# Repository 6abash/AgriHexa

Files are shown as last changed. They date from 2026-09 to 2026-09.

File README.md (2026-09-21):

# AgriHexa

A six-legged agricultural robot: custom carbon-fiber hexapod chassis,
dual-MCU control/kinematics stack, IMU-stabilized walking, and
satellite-image path planning for autonomous fieldwork. Originally
based on the open-source [Make Your Pet](https://github.com/makeyourpet)
platform, substantially redesigned and re-engineered for planting and
terrain navigation.

## Achievements

🏆 **1st Place, Open Category — WRCC 2026**, for outstanding autonomous
performance.

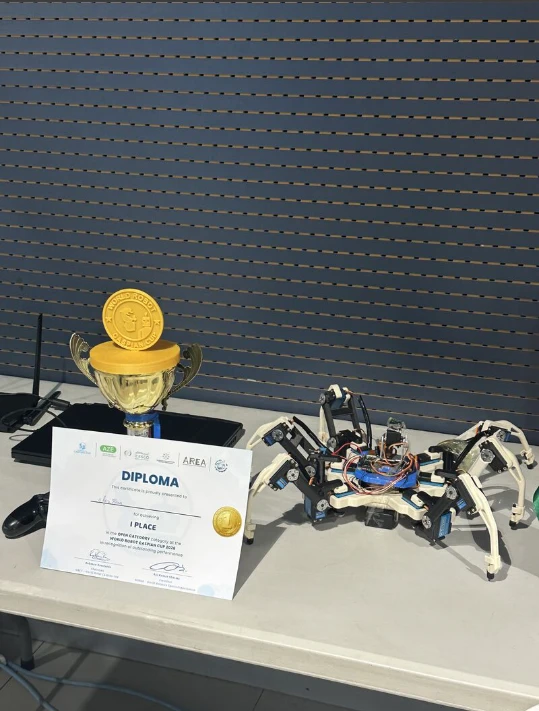
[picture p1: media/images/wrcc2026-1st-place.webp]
AgriHexa — 1st Place, Open Category, WRCC 2026


## Features

- **Planting mechanism** — deploys small (3–5 mm radius) circular
  seeds/plants in a hummus-like growing medium as the robot traverses
  a field.
- **IMU-stabilized walking** — a BNO055 IMU feeds dual PID loops
  (pitch/roll) so the body stays level while walking or standing on
  uneven ground.
- **Autonomous terrain navigation** — an A* planner turns a satellite
  image (e.g. a Google Maps screenshot) into a terrain-cost grid,
  lets an operator drop multiple waypoints, and routes the robot along
  the path with the least incline/decline and roughest terrain.
- **Dual-MCU control** — an ESP32 handles Wi-Fi, PS4 teleop, and IMU
  stability; a Servo2040 (RP2040) is dedicated to per-leg inverse
  kinematics and gait generation.
- **Carbon-fiber legs with steel servo horns**, driven by 18x DS3235
  servos (3 per leg x 6 legs).

## Architecture

```
Satellite image ──▶ [navigation] A* planner ──Wi-Fi (TCP)──▶ [firmware] ESP32
                                                                   │  control + IMU PID
                                                                   │  UART (RobotState)
                                                                   ▼
                                                        [kinematics] Servo2040
                                                          IK solve + gait ──▶ 18x DS3235
```

PS4 controller input always takes priority over autonomous commands —
touching the controller instantly cancels any in-progress autonomous
move.

## Media

<video src="media/videos/short-pitch.mp4" controls width="500"></video>
<video src="media/videos/stability-system.mp4" controls width="500"></video>

## Repository structure

| Path | Contents |
|---|---|
| [`/firmware`](firmware) | ESP32 control MCU: Wi-Fi, PS4 teleop, BNO055 stability PID |
| [`/kinematics`](kinematics) | Servo2040 MCU: per-leg inverse kinematics, tripod gait |
| [`/navigation`](navigation) | Satellite-image A* terrain path planner (ground station) |
| [`/simulation`](simulation) | MATLAB one-leg IK visualizer; full hexapod Simscape model in progress |
| [`/hardware`](hardware) | BOM, [CAD](hardware/cad) (partial, more coming), wiring diagram in progress |
| [`/docs`](docs) | [Design differences from Make Your Pet](docs/design-differences.md) |
| [`/media`](media) | Photos and demo videos |

## Getting started

1. **Firmware (ESP32)** — see [`firmware/README.md`](firmware/README.md)
   for wiring, the `secrets.h` setup, and PlatformIO build steps.
2. **Kinematics (Servo2040)** — see
   [`kinematics/README.md`](kinematics/README.md) for the leg model,
   gait, and CMake/Pico SDK build steps.
3. **Navigation (ground station)** — see
   [`navigation/README.md`](navigation/README.md) to run the A*
   satellite planner.
4. **Simulation** — see [`simulation/README.md`](simulation/README.md)
   for the MATLAB one-leg IK visualizer.

## Credits

- IK/gait approach adapted from the open-source
  [Make Your Pet](https://github.com/makeyourpet) hexapod platform.
- Built by [6abash](https://github.com/6abash).

## License

[MIT](LICENSE)

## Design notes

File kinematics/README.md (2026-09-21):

# Kinematics — Servo2040 Inverse Kinematics MCU

The Servo2040 (RP2040, Pimoroni) is dedicated entirely to leg math and
servo output. It receives a fused `RobotState` packet from the ESP32
over UART every control cycle and turns it into 18 servo angles.

## Leg model

Each leg is a 3-DOF serial chain: coxa (`L1`), femur (`L2`), tibia
(`L3`), solved with closed-form inverse kinematics
(`solve_ik(x, y, z, side)` in `servo2040/main.cpp`):

```
L1 = 4.0   // coxa
L2 = 8.0   // femur
L3 = 12.0  // tibia
```

Given a target foot position in the leg's local frame, `solve_ik`
returns hip/thigh/shin (`h`, `t`, `s`) angles, or marks the target
unreachable (`valid = false`) if it falls outside the leg's workspace
(`d > L2+L3` or `d < |L2-L3|`).

Six legs (`LF`, `LB`, `LM`, `RM`, `RF`, `RB`), three servos each = the
project's 18x DS3235. Per-leg Cartesian trims (`xyz_offset`) let each
leg be calibrated independently to absorb small assembly tolerances,
applied before the IK solve rather than as a post-hoc angle offset.

## Gait

`walk_step()` drives a tripod gait: legs are split into two phase
groups (`gait_offsets`), alternating stance (linear ground contact,
carrying the body) and swing (a quintic Bezier arc lifting the foot by
`STEP_H` and carrying it forward). Body pitch/roll from the ESP32's
IMU PID are folded into every leg's target position every cycle so the
body stays level over uneven ground while walking or standing still
(`stand_still()`).

`startup_sequence()` eases every leg from a folded rest position to
its standing pose over 200 interpolated steps, avoiding a snap-to-pose
power-on jolt.

## UART protocol

Listens on `uart1` (pins 20/21, 115200 baud) for the same packed
`RobotState` struct the ESP32 sends (see
[`/firmware`](../firmware/README.md#protocol)), framed by a `0xAA`
header / `0x55` footer byte pair.

## Building

Requires the [Raspberry Pi Pico SDK](https://github.com/raspberrypi/pico-sdk)
and the [Pimoroni Pico libraries](https://github.com/pimoroni/pimoroni-pico)
(for `ServoCluster`).

```bash
cd kinematics/servo2040
mkdir build && cd build
cmake -DPICO_SDK_PATH=/path/to/pico-sdk \
      -DPIMORONI_PICO_PATH=/path/to/pimoroni-pico ..
make -j4
# flash Hexapod_OS.uf2 to the Servo2040 in BOOTSEL mode
```

Built and tested against Pico SDK 1.5.1.

Alternatively set `PICO_SDK_FETCH_FROM_GIT=ON` /
`PIMORONI_PICO_FETCH_FROM_GIT=ON` to have CMake pull both SDKs
automatically.

## Credit

The IK/gait approach on the Servo2040 builds on ideas from the
open-source [Make Your Pet](https://github.com/makeyourpet) hexapod
platform, substantially reworked for AgriHexa's leg geometry, dual-MCU
split, and Cartesian trim/stability integration.

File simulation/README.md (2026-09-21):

# Simulation

## One-leg IK visualizer (`/one_leg`)

`IK_visualizer.m` is a MATLAB tool for validating the 3-DOF leg
inverse-kinematics solution (hip/thigh/shin) used on the Servo2040
before it ever touches hardware. It renders a single leg in 3D and
gives you live sliders for target X/Y/Z plus a knee-up/knee-down
toggle, redrawing the link chain and annotating each joint angle
(θ_H, θ_T, θ_S) in degrees as you move them. It shares the same
planar-IK-after-hip-rotation approach as `kinematics/servo2040/main.cpp`
(`solve_ik`), so it doubles as a sanity check when leg geometry
(`L2`, `L3`) or the knee convention changes.

```matlab
IK_visualizer
```

## Full hexapod (Simscape) — in progress

The one-leg model has been scaled up into a full hexapod Simscape
Multibody simulation (all 6 legs, body dynamics, gait), currently in
progress. It'll land in this folder once the model is ready, along
with the CAD it's built from.

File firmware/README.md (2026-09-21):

# Firmware — ESP32 Control MCU

The ESP32 is the "brain" of AgriHexa's dual-MCU control stack. It owns
everything that isn't leg math:

- **Stability**: reads a BNO055 IMU and runs two independent PID loops
  (pitch, roll) to compute body-leveling corrections in real time.
- **Teleop**: pairs with a PS4 controller for manual driving (stride,
  strafe, ride height).
- **Autonomy bridge**: runs a TCP server on port 80 that accepts move
  commands (`F`, `B`, `L`, `R`, `FR`, `FL`, `BR`, `BL`, `S`) from the
  ground-station A* planner in [`/navigation`](../navigation), and
  ACKs each completed step back over the socket.
- **Fusion**: packs pitch/roll/stride/strafe/height/walking into a single
  `RobotState` struct and streams it over UART to the Servo2040
  (see [`/kinematics`](../kinematics)), which solves inverse kinematics
  and drives the 18 servos.

PS4 input always takes priority — touching the controller instantly
cancels any in-progress autonomous move.

## Hardware

| Signal | ESP32 Pin |
|---|---|
| I2C SDA (BNO055)| 18 |
| I2C SCL (BNO055)| 21 |
| UART TX -> Servo2040 | 16 |
| UART RX <- Servo2040 | 23 |
| Relay | 27 |

## Building

This is a PlatformIO project.

```bash
cd firmware/esp32
cp include/secrets.h.example include/secrets.h   # fill in your own Wi-Fi creds
pio run -t upload
pio device monitor
```

`secrets.h` is gitignored on purpose — never commit real Wi-Fi
credentials. Only `secrets.h.example` is tracked.

## Protocol

`RobotState` (packed, sent every loop iteration over UART2 @ 115200):

```c
struct __attribute__((packed)) RobotState {
    uint8_t header;      // 0xAA
    float body_pitch;
    float body_roll;
    float body_yaw;
    float stride;
    float strafe;
    float height;
    uint8_t walking;
    uint8_t footer;       // 0x55
};
```

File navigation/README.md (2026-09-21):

# Navigation — Satellite Terrain Path Planner

A ground-station Python tool that lets an operator plan an autonomous
mission for AgriHexa directly on a satellite/aerial image, then drives
the robot through it live over Wi-Fi.

## Pipeline

1. **Image ingestion** — loads a satellite screenshot (e.g. cropped
   from Google Maps) of the target field. If none is found, a synthetic
   terrain photo is generated so the planner can still be demoed.
2. **Terrain costing** — resizes the image to a grid and derives a
   per-cell traversal cost from two cues: an HSV green mask (vegetation
   = easier ground) and Sobel gradient magnitude (roughness = a proxy
   for slope/incline, penalized more heavily). Cells above a threshold
   are marked impassable, so A* is steered around steep terrain and
   obstacles, not just toward the shortest line.
3. **Waypoint selection** — `matplotlib.ginput` lets the operator click
   as many waypoints as they like directly on the satellite image.
4. **Path planning** — 8-connected A* (`a_star_search`) runs between
   each consecutive waypoint pair, using terrain cost (not just
   distance) as the edge weight, so the resulting path favors flat,
   vegetated ground and minimizes climbs/descents.
5. **Mission execution** — the grid path is translated into the
   robot's move vocabulary (`F/B/L/R/FR/FL/BR/BL/S`) and streamed step
   by step over a TCP socket to the ESP32 (see [`/firmware`](../firmware)),
   waiting for an `ACK` after each step before sending the next. A live
   dual-panel animation (satellite view + cost map) tracks the robot's
   position as it moves.

## Running

```bash
cd navigation
pip install -r requirements.txt
python satellite_path_planner.py
```

Set `mock_hardware=True` in the `execute_mission_and_animate` call at
the bottom of the script to dry-run the planner and animation without
an open Wi-Fi socket to real hardware. Update `esp32_ip` to match the
static IP configured in the ESP32 firmware.

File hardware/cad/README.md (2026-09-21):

# CAD

STEP files for AgriHexa's mechanical parts, exported from SolidWorks.
More parts land here as they're finalized — this is a first batch, not
the full assembly.

| File | Part |
|---|---|
| `frame.STEP` | Main body frame |
| `servo_body.STEP` | Servo mounting body |
| `servo_back_hole.STEP` | Servo back-hole mount |
| `coxa_left.STEP` | Left-side coxa (hip) link |
| `coxa_right.STEP` | Right-side coxa (hip) link |
| `femur.STEP` | Femur (thigh) link |
| `tibia.STEP` | Tibia (shin) link |

Note the left/right coxa are separate parts, not a single mirrored
part — keep that in mind if you're assembling or referencing them
elsewhere (e.g. the Simscape model).

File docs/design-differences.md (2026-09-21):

# Design differences from Make Your Pet

AgriHexa uses the open-source [Make Your Pet](https://github.com/makeyourpet)
hexapod as a starting platform — credit to them for open-sourcing the
design. Everything below is what changed to turn it from a
phone-controlled hexapod into a standalone system built for precision
farming.

## The platform is a means to an end

Make Your Pet's design is a hexapod platform; AgriHexa uses that
platform to solve a specific problem — precision farming (targeted
planting, terrain-aware autonomous navigation). The mechanical base
carried over, but almost everything around it changed to support that.

## Removing the phone dependency

The original Make Your Pet build relies entirely on a smartphone: the
Chica app supplies the sensor data (including the IMU) the robot needs
to operate, and the phone also powers the Servo2040. That works for a
demo platform, but it isn't something you can actually deploy as a
farming system — there's no phone in the loop.

To make it a standalone system, AgriHexa adds:

- **An ESP32 as a dedicated control MCU** — replacing the phone as the
  thing that talks Wi-Fi, runs the stability control loop, and accepts
  teleop/autonomous commands.
- **A standalone BNO055 IMU** — replacing the phone's IMU as the
  stability sensor, feeding the ESP32's pitch/roll PID loops directly.
- **A buck converter (7.4V -> 5V)** — since there's no longer a phone
  to charge the Servo2040, and the system now carries more electronics
  (ESP32, IMU) than the original design, a buck converter steps the
  main 7.4V battery rail down to the 5V logic supply those components
  need.

Everything else in the electrical/control architecture — the Servo2040
handling inverse kinematics and driving the servos — follows the same
approach as Make Your Pet.

## Mechanical changes

- **Steel servo horns instead of plastic** — the stock plastic horns
  failed under the stall torque of the DS3235 servos. Steel horns were
  a necessary swap, not a preference.
- **Revised mounting holes** — hole sizing was reworked to 3mm in
  SolidWorks for a more reliable fastener fit.
- **CF-PETG as the print material** — arrived at by trial and error as
  the best-performing material for the structural/printed parts.

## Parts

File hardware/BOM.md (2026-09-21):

# Bill of Materials

Quantities below are derived directly from the design (6 legs x 3
servos, etc.).

| # | Part | Spec / Notes | Qty |
|---|---|---|-----|
| 1 | Servo | DS3235 digital servo | 18 (3 x 6 legs) |
| 2 | Control MCU | ESP32 dev board (Wi-Fi, PS4 teleop, BNO055 stability PID) | 1 |
| 3 | Kinematics MCU | Pimoroni Servo2040 (RP2040, 18-channel servo driver) | 1 |
| 4 | IMU | Adafruit BNO055 breakout | 1 |
| 5 | Buck converter | 7.4V -> 5V, powers ESP32 + BNO055 + logic rail | 1 |
| 6 | Battery | 2S LiPo, 7.4V nominal | 1 |
| 7 | Relay | Switches planting mechanism / auxiliary load off ESP32 GPIO27 | 1 |
| 8 | Servo horn | Steel (replaces stock plastic — failed under DS3235 stall torque) | 18 |
| 9 | Leg tube/link | Carbon fiber | 6 legs x 3 links = 18 |
| 10 | Structural/printed parts | CF-PETG (chosen over plain PETG/PLA by trial and error) | as needed |
| 11 | Controller | PS4 DualShock 4 (teleop) | 1 |
| 12 | Planting mechanism | Servo-driven dispenser for 3–5mm radius plants | 1 |
| 13 | Fasteners | M3 hardware (3mm mounting holes, SolidWorks-revised) | as needed |
| 14 | Wiring | Servo extension leads, JST/XT30 connectors, heat shrink | as needed |

Add rows as the hardware doc / CAD get finalized (mounting hardware,
connectors, standoffs, etc. tend to only become exact once the CAD is
locked).

## Wiring diagram

Not built yet. Recommended tool: **Fritzing** — it has parts for ESP32
dev boards and hobby servos, and produces a breadboard-style diagram
that's far more readable in a README than a raw schematic. Export as
SVG/PNG and drop it here as `hardware/wiring-diagram.svg`, referenced
from the root README.

If a proper schematic (net labels, real symbols for the buck converter,
BNO055, relay) is wanted later, KiCad is the step up from Fritzing.

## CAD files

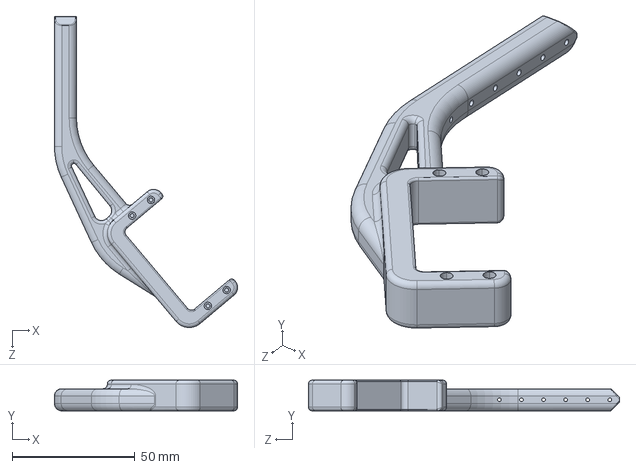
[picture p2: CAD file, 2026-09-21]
hardware/cad/tibia.STEP
74.6 x 12.5 x 126.7 mm

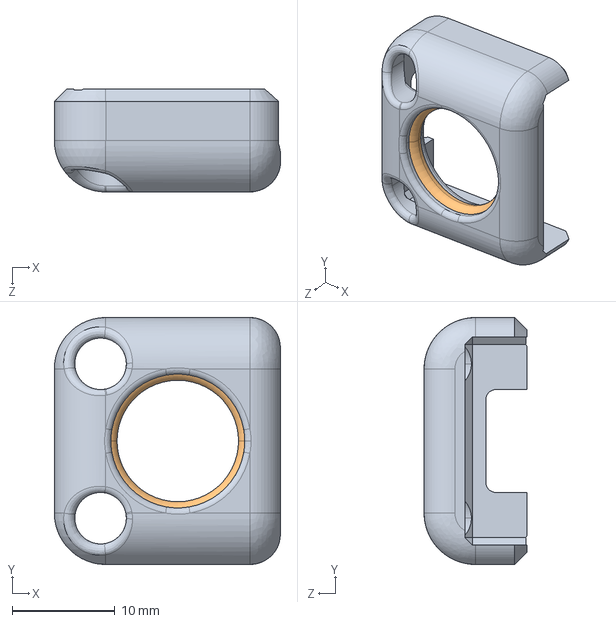
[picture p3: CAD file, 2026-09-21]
hardware/cad/servo_back_hole.STEP
22.0 x 24.0 x 10.0 mm

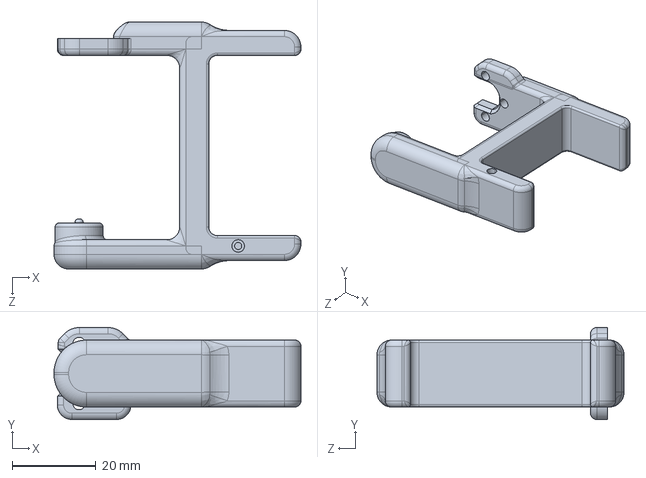
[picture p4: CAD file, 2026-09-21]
hardware/cad/coxa_left.STEP
59.0 x 22.0 x 59.0 mm

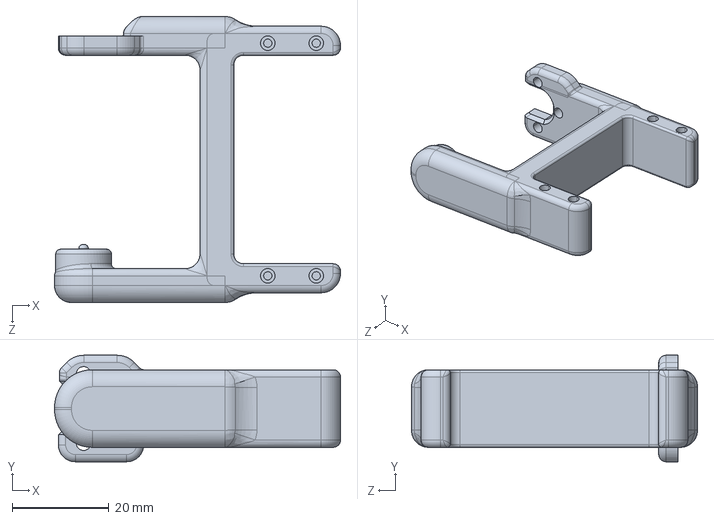
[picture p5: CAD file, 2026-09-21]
hardware/cad/coxa_right.STEP
59.0 x 22.0 x 59.0 mm

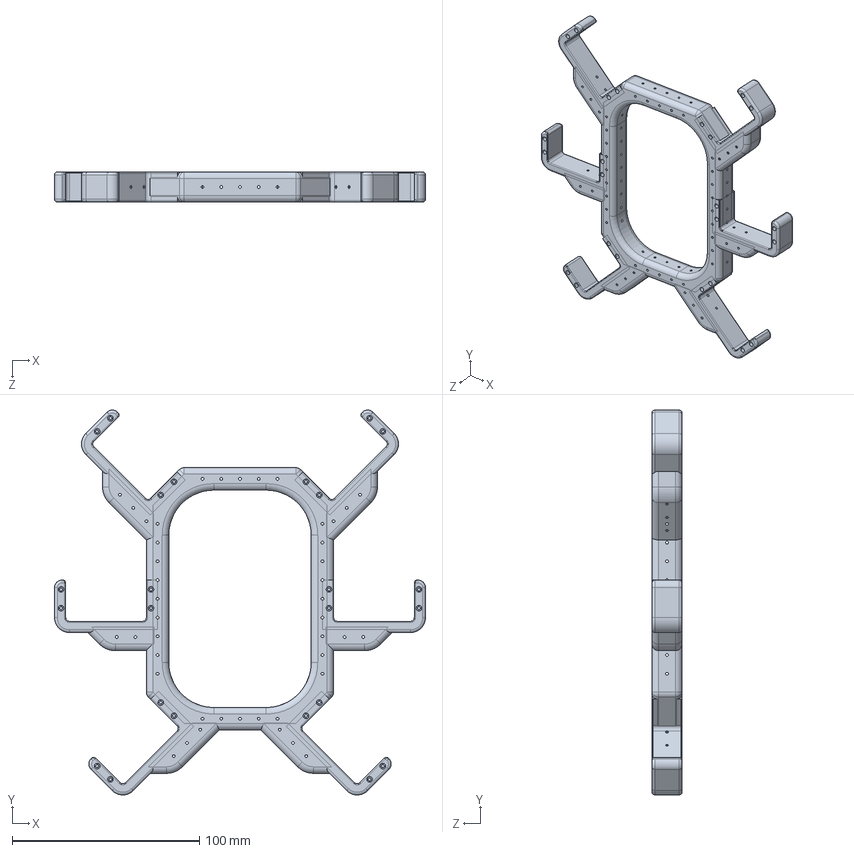
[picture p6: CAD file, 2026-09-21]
hardware/cad/frame.STEP
198.0 x 205.4 x 16.0 mm

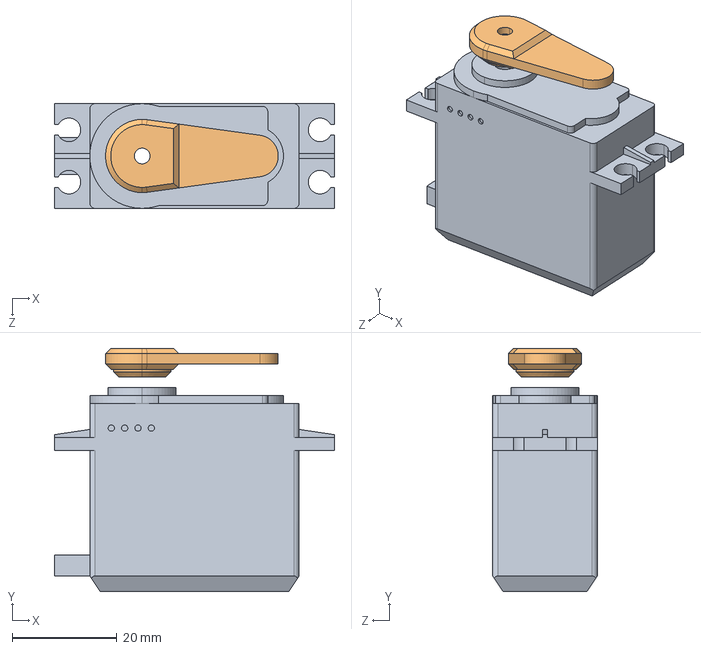
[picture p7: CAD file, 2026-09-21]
hardware/cad/servo_body.STEP
53.5 x 46.5 x 20.0 mm

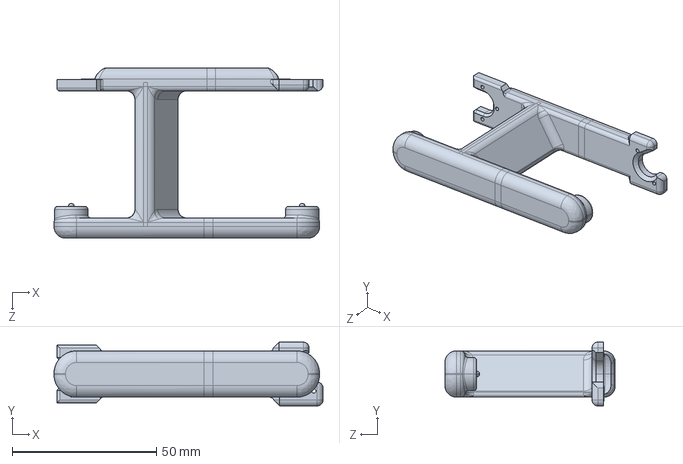
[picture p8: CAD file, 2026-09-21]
hardware/cad/femur.STEP
93.2 x 22.1 x 59.0 mm

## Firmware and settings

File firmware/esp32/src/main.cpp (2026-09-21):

// AgriHexa - ESP32 Control MCU
//
// Responsibilities:
//   - IMU (BNO055) stability PID -> body pitch/roll correction
//   - PS4 controller teleop input
//   - Wi-Fi TCP server accepting autonomous move commands from the
//     ground-station A* planner (see /navigation)
//   - Packs the unified RobotState and streams it over UART to the
//     Servo2040 (see /kinematics), which solves IK and drives the servos
//
#include <Arduino.h>
#include <Wire.h>
#include <Adafruit_Sensor.h>
#include <Adafruit_BNO055.h>
#include <PS4Controller.h>
#include <WiFi.h>
#include "secrets.h"

#define RELAY_PIN    27
#define I2C_SDA      18
#define I2C_SCL      21
#define SERVO_TX     16
#define SERVO_RX     23

// ==========================================
// 1. HARDWARE SENSORS & PID
// ==========================================
float filtered_pitch = 0.0f;
float filtered_roll  = 0.0f;
const float ALPHA    = 0.1f;
const float DEADBAND = 2.0f;

Adafruit_BNO055 bno = Adafruit_BNO055(55, 0x28, &Wire);

struct PID {
    float kp, ki, kd;
    float prev_error;
    float integral;
};

PID pitch_pid = {0.01f, 0.0f, 0.0008f, 0.0f, 0.0f};
PID roll_pid  = {0.01f, 0.0f, 0.0008f, 0.0f, 0.0f};

uint32_t zero_streak = 0;
const uint32_t ZERO_LIMIT = 50;
bool bno_initialized = false;
unsigned long last_time = 0;

float compute_pid(PID &pid, float error, float dt) {
    pid.integral += error * dt;
    pid.integral = constrain(pid.integral, -0.5f, 0.5f);
    float derivative = (error - pid.prev_error) / dt;
    derivative = constrain(derivative, -50.0f, 50.0f);
    pid.prev_error = error;
    return (pid.kp * error) + (pid.ki * pid.integral) + (pid.kd * derivative);
}

void attempt_recovery() {
    Serial.println("[BNO055] Resetting...");
    bno_initialized = false;
    Wire.end(); delay(500);
    Wire.begin(I2C_SDA, I2C_SCL); Wire.setClock(100000); delay(100);
    if (bno.begin()) {
        bno.setExtCrystalUse(true);
        bno_initialized = true;
        zero_streak = 0;
        Serial.println("[BNO055] Recovery successful.");
    }
}

// ==========================================
// 2. KINEMATICS DATA STRUCTURE
// ==========================================
struct __attribute__((packed)) RobotState {
    uint8_t header;
    float body_pitch;
    float body_roll;
    float body_yaw;
    float stride;
    float strafe;
    float height;
    uint8_t walking;
    uint8_t footer;
};

RobotState state = {0xAA, 0.0f, 0.0f, 0.0f, 0.0f, 0.0f, -12.0f, 0, 0x55};

// ==========================================
// 3. NETWORK & NON-BLOCKING VARIABLES
// ==========================================
const char* ssid     = WIFI_SSID;
const char* password = WIFI_PASSWORD;

// Static IP for the robot on the field network
IPAddress local_IP(192, 168, 0, 51);
IPAddress gateway(192, 168, 0, 1);
IPAddress subnet(255, 255, 255, 0);

WiFiServer server(80);
WiFiClient active_client; // Persistent TCP client

// Non-blocking timer variables
const unsigned long STRIDE_DELAY_MS = 1500;
unsigned long moveStartTime = 0;
bool isAutoMoving = false; // Tracks if a Wi-Fi command is currently executing
float auto_stride = 0.0f;
float auto_strafe = 0.0f;

// ==========================================
// 4. PS4 CONTROLLER
// ==========================================
float ps4_stride = 0.0f;
float ps4_strafe = 0.0f;
float height_cmd = -12.0f;
bool  ps4_walking = false;

const float DEAD_ZONE     = 10.0f;
const float STRIDE_SCALE  = 0.007f;
const float STRAFE_SCALE  = -0.007f;
const float HEIGHT_SCALE  = 0.04f;
const float HEIGHT_MIN    = -18.0f;
const float HEIGHT_MAX    = -6.0f;

void read_ps4() {
    if (!PS4.isConnected()) return;
    float lx = PS4.LStickX();
    float ly = PS4.LStickY();
    float ry = PS4.RStickY();

    if (fabsf(ly) > DEAD_ZONE) ps4_stride = constrain(-ly * STRIDE_SCALE, -1.0f, 1.0f);
    else ps4_stride = 0.0f;

    if (fabsf(lx) > DEAD_ZONE) ps4_strafe = constrain(lx * STRAFE_SCALE, -1.0f, 1.0f);
    else ps4_strafe = 0.0f;

    ps4_walking = (fabsf(ly) > DEAD_ZONE) || (fabsf(lx) > DEAD_ZONE);

    if (fabsf(ry) > DEAD_ZONE) {
        height_cmd = constrain(height_cmd + (-ry) * HEIGHT_SCALE * 0.01f, HEIGHT_MIN, HEIGHT_MAX);
    }
}

// ==========================================
// SETUP ROUTINE
// ==========================================
void setup() {
    Serial.begin(115200);

    // Servo UART bridge to the Servo2040: SERVO_RX is where the ESP32
    // receives, SERVO_TX is where the ESP32 transmits.
    Serial2.begin(115200, SERIAL_8N1, SERVO_RX, SERVO_TX);

    // Initialize Hardware Peripherals
    Wire.begin(I2C_SDA, I2C_SCL);
    if (bno.begin()) {
        bno.setExtCrystalUse(true);
        bno_initialized = true;
    }

    // Initialize PS4 with a dummy MAC to prevent crashing
    PS4.begin("03:03:03:03:03:03");

    // Network Setup
    if (!WiFi.config(local_IP, gateway, subnet)) {
        Serial.println("STA Failed to configure static IP");
    }
    WiFi.begin(ssid, password);
    Serial.print("Connecting to Wi-Fi...");
    while (WiFi.status() != WL_CONNECTED) { delay(500); Serial.print("."); }

    Serial.println("\nWiFi Connected! IP: ");
    Serial.println(WiFi.localIP());
    server.begin();
    Serial.println("Awaiting autonomous Python commands on Port 80...");
}

// ==========================================
// MAIN LOOP: WiFi + PS4 + PID
// ==========================================
void loop() {
    // 1. Read PS4 Controller First
    read_ps4();

    // 2. Wi-Fi Control (Non-Blocking)
    // Only accept incoming commands if PS4 is idle
    if (ps4_stride == 0.0f && ps4_strafe == 0.0f) {

        // Grab incoming connection if none is active
        if (!active_client || !active_client.connected()) {
            active_client = server.available();
        }

        // Listen for new commands ONLY if the robot is not currently taking a step
        if (active_client && active_client.connected() && !isAutoMoving) {
            if (active_client.available() > 0) {
                String input = active_client.readStringUntil('\n');
                input.trim();

                if (input.length() > 0) {
                    Serial.println("[Python Command]: " + input);

                    // Map Python commands to temporary kinematics variables
                    if (input == "F") { auto_stride = 1.0f; auto_strafe = 0.0f; isAutoMoving = true; }
                    else if (input == "B") { auto_stride = -1.0f; auto_strafe = 0.0f; isAutoMoving = true; }
                    else if (input == "L") { auto_stride = 0.0f; auto_strafe = -1.0f; isAutoMoving = true; }
                    else if (input == "R") { auto_stride = 0.0f; auto_strafe = 1.0f; isAutoMoving = true; }
                    else if (input == "FR") { auto_stride = 0.707f; auto_strafe = 0.707f; isAutoMoving = true; }
                    else if (input == "FL") { auto_stride = 0.707f; auto_strafe = -0.707f; isAutoMoving = true; }
                    else if (input == "BR") { auto_stride = -0.707f; auto_strafe = 0.707f; isAutoMoving = true; }
                    else if (input == "BL") { auto_stride = -0.707f; auto_strafe = -0.707f; isAutoMoving = true; }
                    else if (input == "S") { auto_stride = 0.0f; auto_strafe = 0.0f; isAutoMoving = false; }

                    if (isAutoMoving) {
                        moveStartTime = millis(); // Start the non-blocking timer
                    } else {
                        active_client.println("ACK"); // Send immediate ACK if just commanded to stop
                    }
                }
            }
        }
    } else {
        // If the user touches the PS4 controller, immediately cancel autonomous movement
        isAutoMoving = false;
        auto_stride = 0.0f;
        auto_strafe = 0.0f;
    }

    // 3. Check if the non-blocking stride has finished
    if (isAutoMoving) {
        if (millis() - moveStartTime >= STRIDE_DELAY_MS) {
            // Step complete! Send ACK back to the laptop
            if (active_client.connected()) {
                active_client.println("ACK");
            }
            // Halt autonomous movement
            isAutoMoving = false;
            auto_stride = 0.0f;
            auto_strafe = 0.0f;
        }
    }

    // 4. Process BNO055 Stability PID
    if (!bno_initialized) { attempt_recovery(); delay(100); return; }

    unsigned long now = millis();
    float dt = (now - last_time) / 1000.0f;

    // Only compute PID if enough time has passed
    if (dt >= 0.02f) {
        last_time = now;

        sensors_event_t event;
        bno.getEvent(&event, Adafruit_BNO055::VECTOR_EULER);

        filtered_pitch = ALPHA * event.orientation.z + (1.0f - ALPHA) * filtered_pitch;
        filtered_roll  = ALPHA * event.orientation.y + (1.0f - ALPHA) * filtered_roll;

        float p_out = compute_pid(pitch_pid, (fabs(filtered_pitch) > DEADBAND ? -filtered_pitch : 0.0f), dt);
        float r_out = compute_pid(roll_pid,  (fabs(filtered_roll) > DEADBAND ? -filtered_roll : 0.0f), dt);

        state.body_pitch = constrain(p_out, -0.3f, 0.3f);
        state.body_roll  = constrain(r_out, -0.3f, 0.3f);
    }

    // 5. Update Unified State (Auto overrides PS4, unless PS4 is actively used)
    state.stride  = isAutoMoving ? auto_stride : ps4_stride;
    state.strafe  = isAutoMoving ? auto_strafe : ps4_strafe;
    state.height  = height_cmd;
    state.walking = (isAutoMoving || ps4_walking) ? 1 : 0;

    // Transmit constantly to Servo2040 so the PID remains responsive
    Serial2.write((uint8_t*)&state, sizeof(RobotState));
}

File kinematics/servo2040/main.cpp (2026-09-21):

// AgriHexa - Servo2040 Inverse Kinematics MCU
//
// Receives the fused RobotState from the ESP32 over UART, solves 3-DOF
// inverse kinematics per leg (coxa/femur/tibia), generates the tripod
// gait swing trajectory (quintic Bezier), and drives all 18 DS3235
// servos via the Pimoroni ServoCluster.
//
#include <stdio.h>
#include <math.h>
#include <cstring>
#include <vector>
#include <algorithm>
#include "pico/stdlib.h"
#include "hardware/uart.h"
#include "drivers/servo/servo_cluster.hpp"

using namespace servo;

#define UART_ID    uart1
#define UART_BAUD  115200
#define PIN_TX     20
#define PIN_RX     21

const float L1 = 4.0, L2 = 8.0, L3 = 12.0;

struct LegConfig {
    const char* name;
    uint8_t pins[3];
    float xyz_offset[3]; // Cartesian trim: X, Y, Z — applied BEFORE solve_ik
    int side_sign;
};

struct Angles {
    float h, t, s;
    bool valid;
};

struct __attribute__((packed)) RobotState {
    uint8_t header;
    float body_pitch;
    float body_roll;
    float body_yaw;
    float stride;
    float strafe;
    float height;
    uint8_t walking;
    uint8_t footer;
};

float body_height  = -12.0f;
float body_roll    =   0.0f;
float body_pitch   =   0.0f;
float stride_scale =   0.0f;
float strafe_scale =   0.0f;
bool  walking      =   false;

bool first_packet_received = false;

// Cartesian per-leg trim — adjust these to physically calibrate each leg's resting position.
// X = forward(+)/back(-), Y = outward(+)/inward(-), Z = up(+)/down(-)
LegConfig leg_data[6] = {
    {"LF", {0,  1,  2},  {0.0f, 4.0f, -2.5f}, -1},
    {"LB", {3,  4,  5},  {0.0f, 4.0f, 0.0f}, -1},
    {"LM", {6,  7,  8},  {0.0f, 4.0f, -1.7f}, -1},
    {"RM", {9,  10, 11}, {0.0f, 0.0f, 0.0f}, -1},
    {"RF", {12, 13, 14}, {0.0f, 0.0f, 0.0f}, -1},
    {"RB", {15, 16, 17}, {0.0f, 0.0f, 0.0f}, -1}
};

const float LEG_SIDE[6] = { 1.0f,  1.0f,  1.0f, -1.0f, -1.0f, -1.0f};
const float PITCH_GAIN  = 2.0f;
const float ROLL_GAIN   = 2.0f;
const float Y_OFFSET    = 8.0f;
const float FREQ        = 1.0f;
const float STEP_H      = 8.0f;
const float LEG_X_POS[6] = { 5.0f, -5.0f,  0.0f,  0.0f,  5.0f, -5.0f};
const float LEG_Y_POS[6] = { 8.0f,  8.0f,  8.0f,  8.0f,  8.0f,  8.0f};
float gait_offsets[6] = {0.0, 0.0, 0.5, 0.0, 0.5, 0.5};

void uart_init_comms() {
    uart_init(UART_ID, UART_BAUD);
    gpio_set_function(PIN_TX, GPIO_FUNC_UART);
    gpio_set_function(PIN_RX, GPIO_FUNC_UART);
    uart_set_format(UART_ID, 8, 1, UART_PARITY_NONE);
    uart_set_fifo_enabled(UART_ID, true);
}

void read_uart_packets() {
    static uint8_t buf[sizeof(RobotState)];
    static int idx = 0;
    while (uart_is_readable(UART_ID)) {
        uint8_t byte = uart_getc(UART_ID);
        if (byte == 0xAA && idx != 0) idx = 0;
        if (idx == 0 && byte != 0xAA) continue;
        buf[idx++] = byte;
        if (idx == sizeof(RobotState)) {
            idx = 0;
            RobotState* rs = (RobotState*)buf;
            if (rs->header == 0xAA && rs->footer == 0x55) {
                body_pitch = rs->body_pitch; body_roll = rs->body_roll;
                stride_scale = rs->stride; strafe_scale = rs->strafe;
                body_height = rs->height; walking = (rs->walking == 1);
                first_packet_received = true;
            }
        }
    }
}

Angles solve_ik(float x, float y, float z, int side) {
    float actual_y = y * (float)side;
    float theta1 = atan2(actual_y, x);
    float r = sqrt(x*x + actual_y*actual_y) - L1;
    float d = sqrt(r*r + z*z);
    if (d > (L2 + L3) || d < fabs(L2 - L3)) return {0, 0, 0, false};
    float cos_t3 = (d*d - L2*L2 - L3*L3) / (2 * L2 * L3);
    float theta3 = acos(std::max(-1.0f, std::min(1.0f, cos_t3)));
    float a1 = atan2(z, r);
    float a2 = acos(std::max(-1.0f, std::min(1.0f, (L2*L2 + d*d - L3*L3) / (2 * L2 * d))));
    return {(float)(theta1 * 180.0 / M_PI), (float)((a1 + a2) * 180.0 / M_PI), (float)(90.0 - (theta3 * 180.0 / M_PI)), true};
}

float bezier5(float t, float p0, float p1, float p2, float p3, float p4, float p5) {
    float mt = 1.0f - t;
    return (pow(mt,5)*p0 + 5*pow(mt,4)*t*p1 + 10*pow(mt,3)*pow(t,2)*p2 + 10*pow(mt,2)*pow(t,3)*p3 + 5*mt*pow(t,4)*p4 + pow(t,5)*p5);
}

void set_leg(ServoCluster& cluster, LegConfig& leg, int i, Angles res) {
    if (!res.valid) return;
    float h = res.h; float t = res.t; float s = res.s; // no more post-IK degree trims
    if (i <= 2) { cluster.value(leg.pins[0], h); cluster.value(leg.pins[1], t); cluster.value(leg.pins[2], -s); }
    else { cluster.value(leg.pins[0], h); cluster.value(leg.pins[1], -t); cluster.value(leg.pins[2], s); }
}

void stand_still(ServoCluster& cluster) {
    for (int i = 0; i < 6; i++) {
        float roll_z  = LEG_SIDE[i] * Y_OFFSET * ROLL_GAIN * sinf(body_roll);
        float roll_y  = LEG_Y_POS[i] * (cosf(body_roll) - 1.0f);
        float pitch_z = LEG_X_POS[i] * PITCH_GAIN * sinf(body_pitch);
        float pitch_x = LEG_X_POS[i] * (cosf(body_pitch) - 1.0f);

        float final_x = pitch_x;
        float final_y = Y_OFFSET + roll_y;
        float final_z = body_height + roll_z + pitch_z;

        if (i < 3) final_x = -final_x;

        // Apply Cartesian trim BEFORE solving IK
        final_x += leg_data[i].xyz_offset[0];
        final_y += leg_data[i].xyz_offset[1];
        final_z += leg_data[i].xyz_offset[2];

        Angles res = solve_ik(final_x, final_y, final_z, leg_data[i].side_sign);
        set_leg(cluster, leg_data[i], i, res);
    }
}
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

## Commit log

2026-08-03 Create README.md
    Overview & Architecture
    The firmware is structured to receive high-level body pose and gait commands via UART from an external master controller (such as an ESP32), process them through real-time mathematical models, and ou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
2026-09-21 Add firmware, kinematics, and navigation modules
    Scaffold the repo with the dual-MCU control stack (ESP32 firmware +
    Servo2040 inverse kinematics/gait), the satellite A* terrain path
    planner, and a rewritten README documenting the full feature set and
    architecture. WiFi credentials in the ESP32 firmware are moved to a
    gitignored secrets.h so they never land in the public repo.
    Claude-Session: https://claude.ai/code/session_01YV9puBguhQb8V6AXMzBFPd
2026-09-21 Add simulation, hardware BOM, design docs, and media
    - simulation: one-leg MATLAB IK visualizer, notes full Simscape
    hexapod model is in progress
    - hardware: BOM derived from the design (18 servos, dual-MCU, etc.)
    and a wiring-diagram placeholder/recommendation
    - docs: write-up of what differs from the Make Your Pet base platform
    (standalone ESP32 + IMU replacing the phone, buck converter, steel
    horns, CF-PETG)
    - media: pitch and stability-system videos, WRCC 2026 1st place photo
    - kinematics: swap the placeholder CMakeLists for the real one
    (genericized to drop machine-specific absolute paths)
    Claude-Session: https://claude.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
2026-09-21 Add first batch of CAD parts, drop BOM costs
    - hardware/cad: frame, servo body, left/right coxa, femur STEP files
    (more submissions to follow)
    - BOM: remove unit/total cost columns per request
    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
    [coxa_left.STEP, coxa_right.STEP, femur.STEP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]
2026-09-21 Add servo back-hole and tibia CAD parts
    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
    [servo_back_hole.STEP, tibia.STEP]
